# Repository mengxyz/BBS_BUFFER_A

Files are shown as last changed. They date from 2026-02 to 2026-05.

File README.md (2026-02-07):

# BBS_BUFFER_A
### BAMBU Filament Buffer alternative with super cheap component
Minimal, fast, and hardware‑focused firmware for the CH32V003.  
This project currently ships a clean **ADC → PWM** control loop with **button‑driven calibration** stored in flash.

Built with GPT Codex 5.2.

Based on the original BBS Buffer A project: `https://github.com/4061N/BBS-Buffer-A`

## Highlights
- 10‑bit ADC read on PA2, mapped to PWM duty.
- PWM output on PC4 (TIM1 CH4) by default.
- Short/long press calibration on PC1:
  - Short press → save **min ADC**
  - Long press → save **max ADC**
- Calibration stored in on‑chip flash (EEPROM‑style).
- UART debug prints on PD5 (115200 8N1).

## Quick Start (PlatformIO)
From repo root:
```bash
pio run -e genericCH32V003A4M6
pio run -t upload -e genericCH32V003A4M6
```

## Pin Map (current firmware)
- **PA2**: ADC input
- **PC4**: PWM output (TIM1 CH4)
- **PC1**: Button input (internal pull‑up, active‑low)
- **PD5**: UART TX (115200 8N1)
- **PC2**: WS2812 data (optional, not used by default)

## Calibration Behavior
On **button release**:
- Press < `BUTTON_LONG_MS` → save min ADC
- Press ≥ `BUTTON_LONG_MS` → save max ADC

Saved values are written to the **last flash page** and loaded on boot.  
If flash data is invalid, firmware falls back to defaults.

## Key Config Macros (src/main.c)
- `USE_CALC` — enable/disable flash calibration
- `UART_ENABLE` — UART debug prints
- `PWM_USE_PC4` — choose PWM pin (PC4 vs PA1)
- `ADC_MIN_DEFAULT`, `ADC_MAX_DEFAULT` — fallback range
- `BUTTON_LONG_MS` — long‑press threshold

## Files of Interest
- `src/main.c` — main control loop
- `src/calibration.c` / `include/calibration.h` — flash storage helpers

## Notes
Flash writes erase a full page. Avoid saving excessively in tight loops.

## Recommended 3D Model
[BBS Buffer A XMCU Series Buffer 3D model](https://makerworld.com/en/models/2035894-bbs-buffer-a-xmcu-series-buffer#profileId-2196013)

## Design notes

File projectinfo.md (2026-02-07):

project ported bbs_buffer in /ref folder form ch32v203 to ch32v003

pin def
PC1 OL_ADC
PC2 SYS_RGB
PC4 ADC_1 choose once PC4 / PA1 use to read HALL voltage
PA1 ADC_2
PA2 HALL_OUT pwm out
PD1 programing pin -> UART TX for debug

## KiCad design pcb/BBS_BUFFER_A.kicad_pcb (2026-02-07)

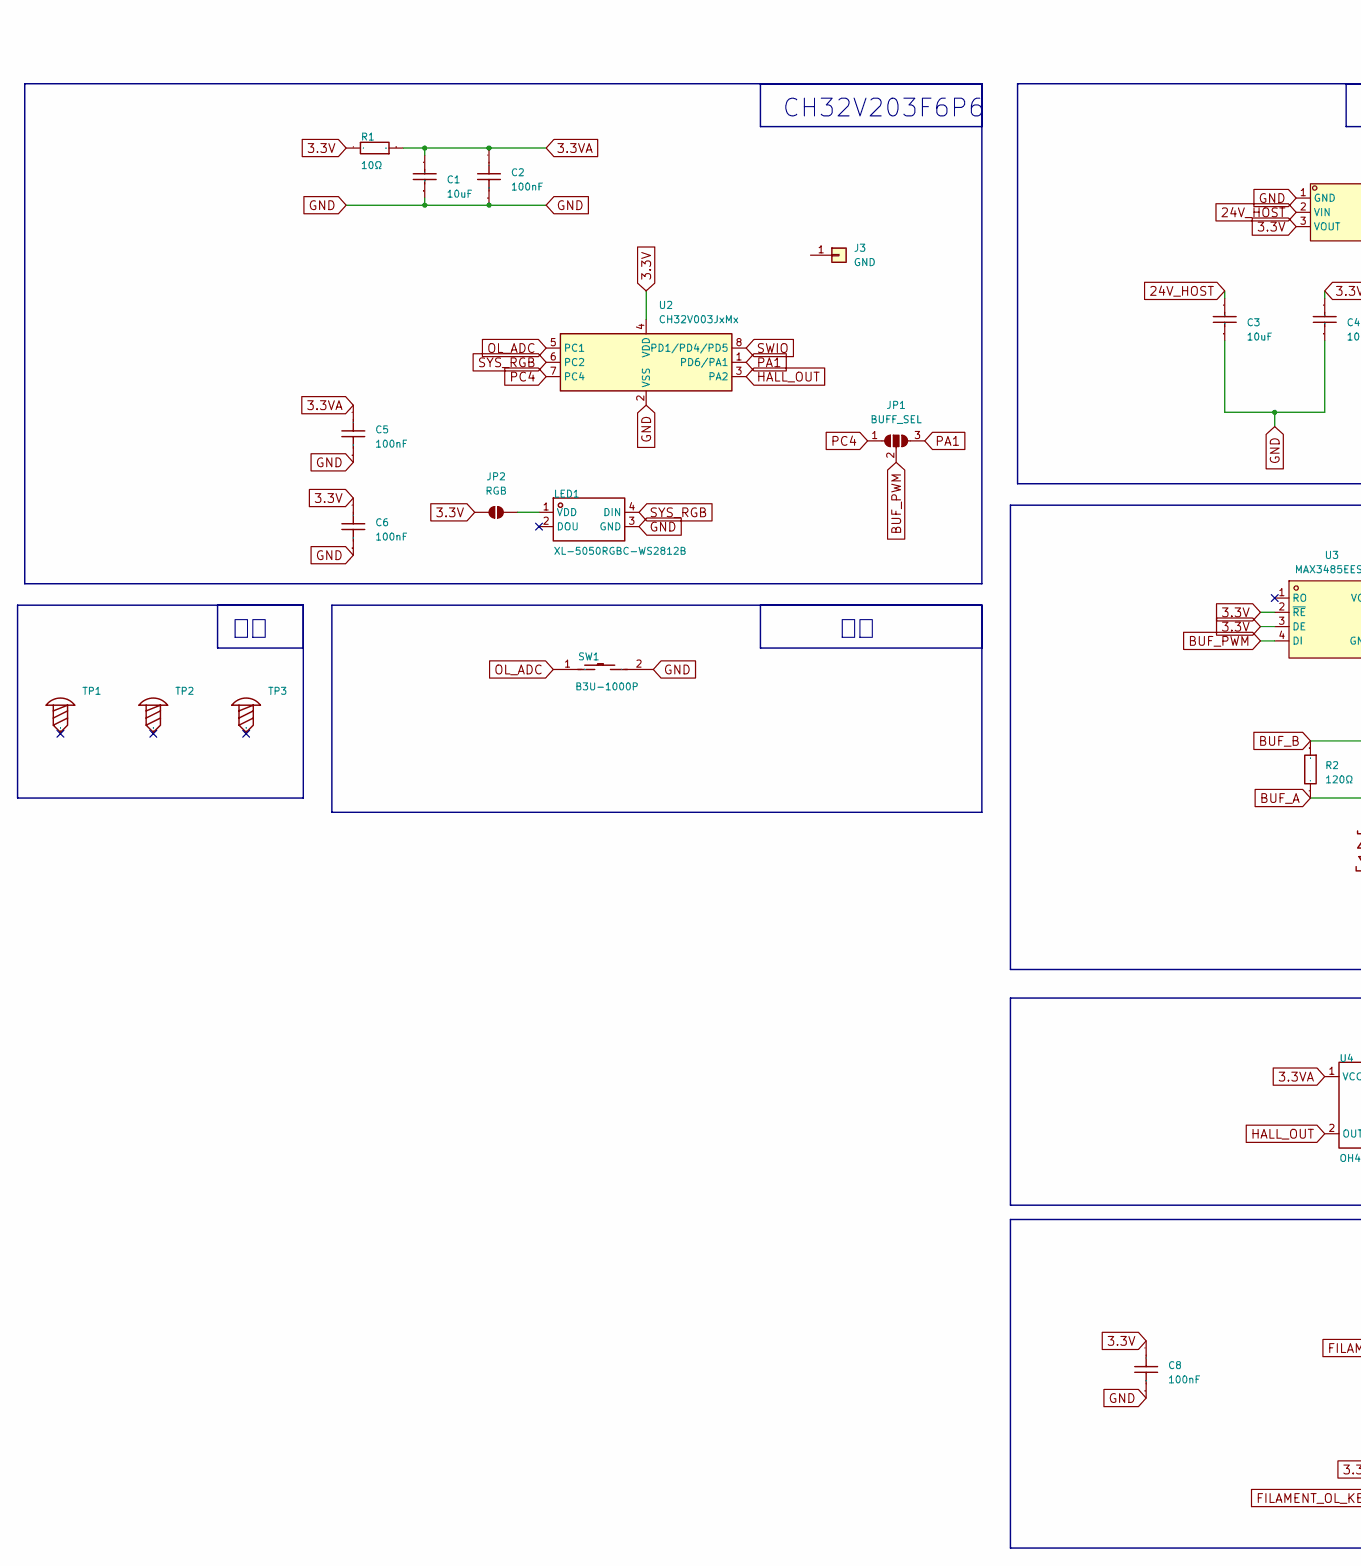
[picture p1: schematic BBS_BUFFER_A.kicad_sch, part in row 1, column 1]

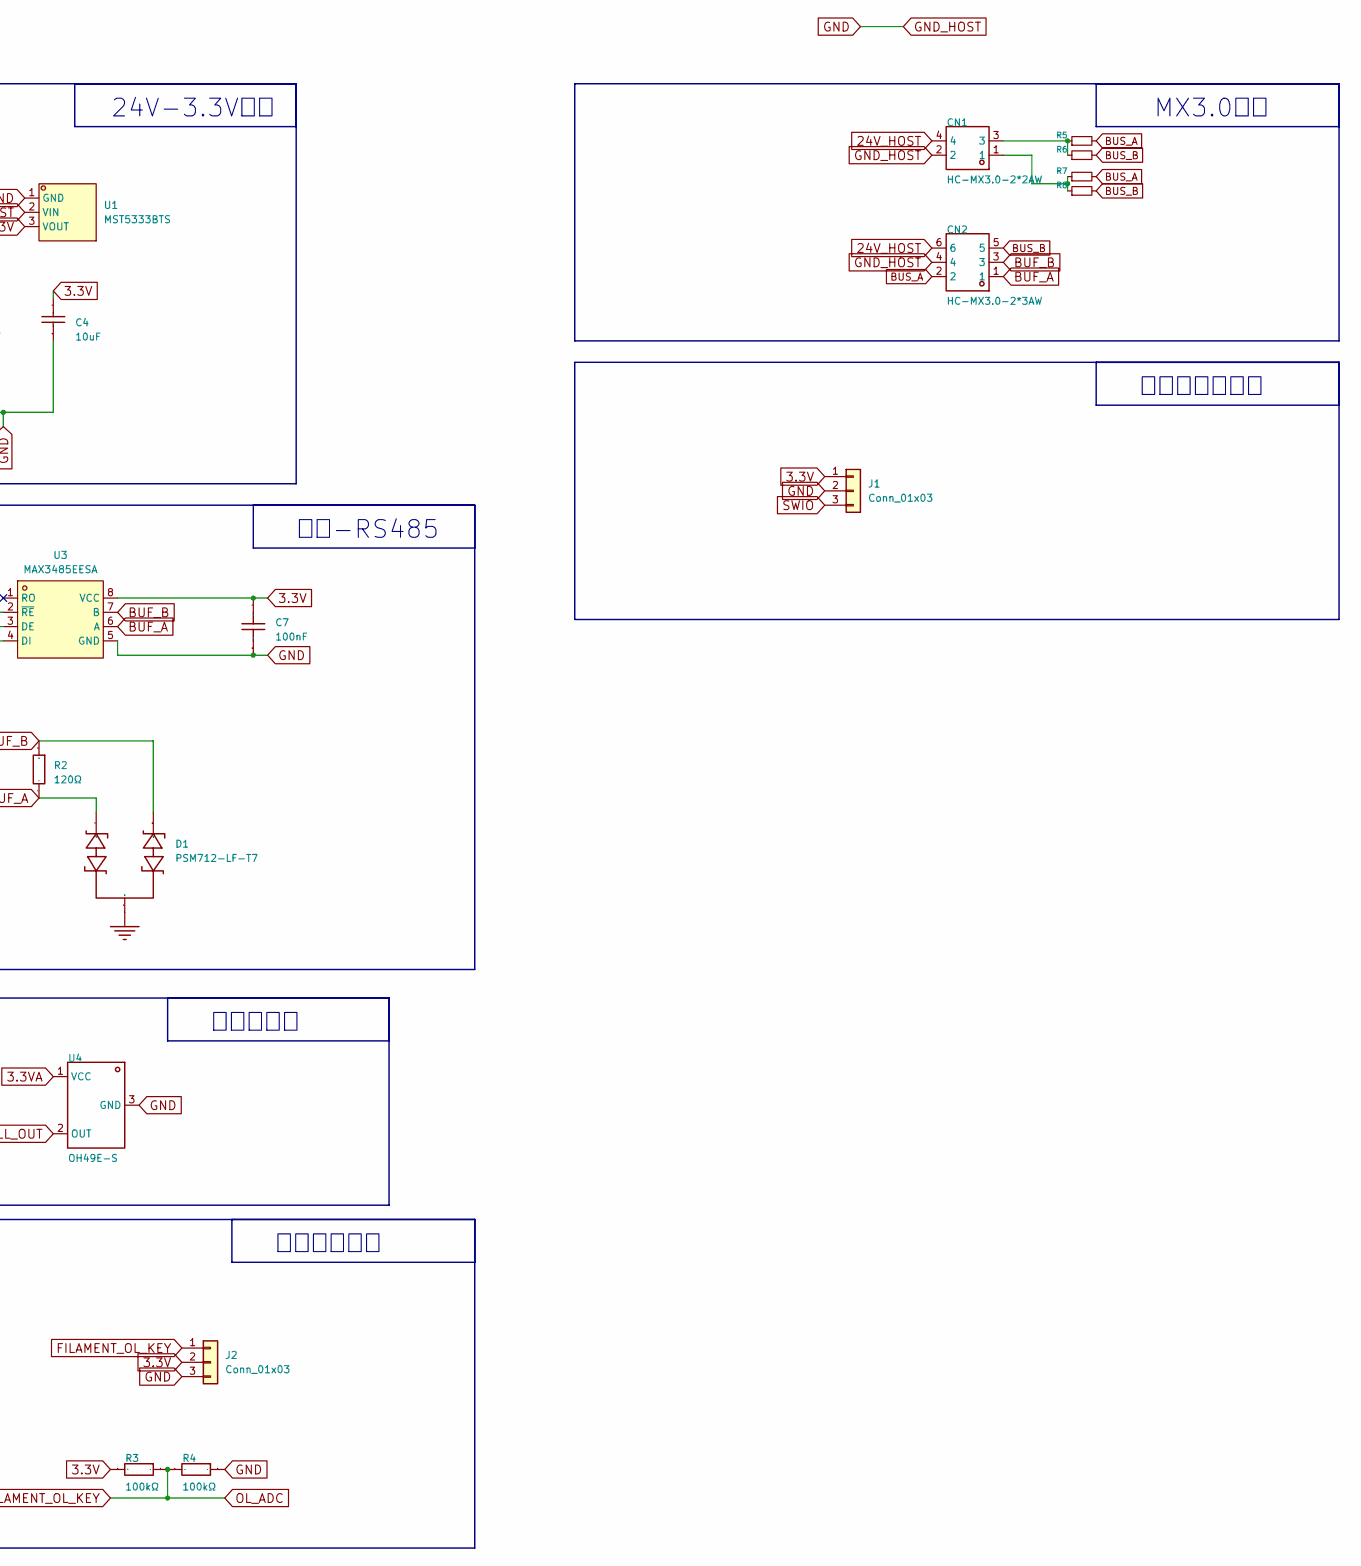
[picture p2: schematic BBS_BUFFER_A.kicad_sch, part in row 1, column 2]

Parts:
C1, C3, C4: 10uF; C_1206_3216Metric; Manufacturer Part CL31A106KBHNNNE; LCSC Part Name 10uF ±10% 50V
C2, C5, C6, C7, C8: 100nF; C_0603_1608Metric; Tolerance ±10%; Voltage Rated 50V; Manufacturer Part CC0603KRX7R9BB104; LCSC Part Name 100nF ±10% 50V
CN1: HC-MX3.0-2*2AW; CONN-TH_4P-P3.00_HC-MX3.0-2X2AW_1; Manufacturer Part HC-MX3.0-2*2AW; LCSC Part Name 2x2P 间距:3mm 弯插 系列:Micro-Fit(MX 3.0)
CN2: HC-MX3.0-2*3AW; CONN-TH_6P-P3.00_HC-MX3.0-2X3AW_1; Manufacturer Part HC-MX3.0-2*3AW; LCSC Part Name 2x3P 间距:3mm 弯插 系列:Micro-Fit(MX 3.0)
D1: PSM712-LF-T7; SOT-23-3_L3.0-W1.7-P0.95-LS2.9-BR; Manufacturer Part PSM712-LF-T7; LCSC Part Name PSM712-LF-T7
J1, J2: Conn_01x03; PinHeader_1x03_P2.54mm_Vertical
J3: GND; PinHeader_1x01_P2.54mm_Vertical
JP1: BUFF_SEL; SolderJumper-3_P2.0mm_Open_TrianglePad1.0x1.5mm
JP2: RGB; R_0402_1005Metric
LED1: XL-5050RGBC-WS2812B; LED-SMD_4P-L5.0-W5.0-BL_XL-5050RGBC; Manufacturer Part XL-5050RGBC-WS2812B; LCSC Part Name XL-5050RGBC-WS2812B
R1: 10Ω; C_0603_1608Metric; Manufacturer Part 0603WAF100JT5E; LCSC Part Name 10Ω ±1% 100mW 厚膜电阻
R2: 120Ω; R_0603_1608Metric; Manufacturer Part 0603WAF1200T5E; LCSC Part Name 120Ω ±1% 100mW 厚膜电阻
R3, R4: 100kΩ; R_0603_1608Metric; Manufacturer Part 0603WAF1003T5E; LCSC Part Name 100kΩ ±1% 100mW 厚膜电阻
R5, R6, R7, R8: R_0402_1005Metric
SW1: B3U-1000P; SW-SMD_L4.0-W3.0-LS5.0; Manufacturer Part B3U-1000P; LCSC Part Name B3U-1000P
TP1, TP2, TP3: MountingHole_2.2mm_M2_DIN965
U1: MST5333BTS; SOT-89-3_L4.5-W2.5-P1.50-LS4.2-BR; LCSC Part C324582
U2: CH32V003JxMx; JEITA_SOIC-8_3.9x4.9mm_P1.27mm
U3: MAX3485EESA; SOIC-8_L4.9-W3.9-P1.27-LS6.0-BL; LCSC Part C9943
U4: OH49E-S; SOT-23-3_L2.9-W1.6-P1.90-LS2.8-BR; Manufacturer Part OH49E-S; LCSC Part Name 线性霍尔开关电路

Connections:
3.3V: C4.2, C6.2, C7.2, C8.2, J1.1, J2.2, JP2.1 (A), R1.2, R3.2, U1.3 (VOUT), U2.4 (VDD), U3.2 (~RE), U3.3 (DE), U3.8 (VCC)
3.3VA: C1.2, C2.2, C5.2, R1.1, U4.1 (VCC)
24V_HOST: C3.2, CN1.4, CN2.6, U1.2 (VIN)
BUF_A: CN2.1, D1.2 (A1), R2.2, U3.6 (A)
BUF_B: CN2.3, D1.1 (A1), R2.1, U3.7 (B)
BUF_PWM: JP1.2 (C), U3.4 (DI)
BUS_A: CN2.2, R5.2, R7.2
BUS_B: CN2.5, R6.2, R8.2
FILAMENT_OL_KEY: J2.1, R3.1, R4.2, SW1.1, U2.5 (PC1)
GND: C1.1, C2.1, C3.1, C4.1, C5.1, C6.1, C7.1, C8.1, CN1.2, CN2.4, D1.3 (K), J1.2, J2.3, LED1.3 (GND), R4.1, SW1.2, U1.1 (GND), U2.2 (VSS), U3.5 (GND), U4.3 (GND)
HALL_OUT: U2.3 (PA2), U4.2 (OUT)
unnamed: CN1.1, R7.1, R8.1
unnamed: CN1.3, R5.1, R6.1
unnamed: JP2.2 (B), LED1.1 (VDD)
PA1: JP1.3 (B), U2.1 (PD6/PA1)
PC4: JP1.1 (A), U2.7 (PC4)
SWIO: J1.3, U2.8 (PD1/PD4/PD5)
SYS_RGB: LED1.4 (DIN), U2.6 (PC2)

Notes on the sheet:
烧录和调试接口
耗材断料检测
霍尔传感器
MX3.0接口
CH32V203F6P6
串口-RS485
24V-3.3V电源

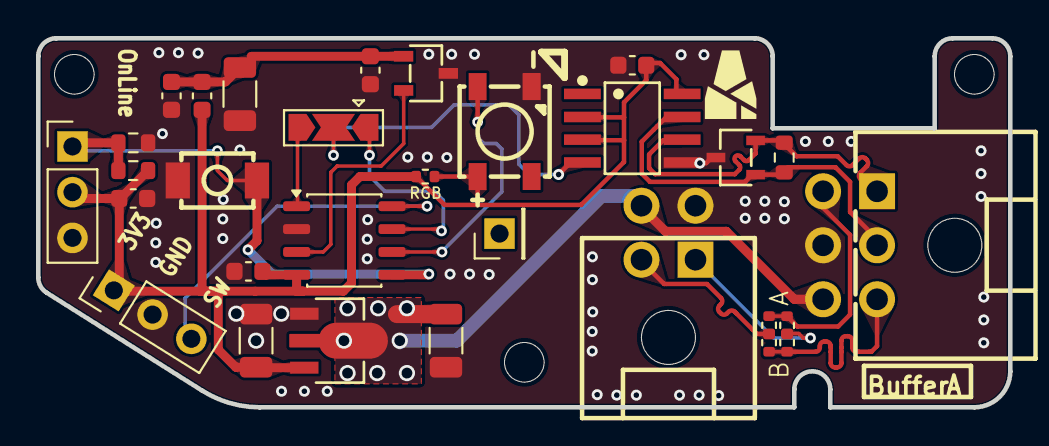
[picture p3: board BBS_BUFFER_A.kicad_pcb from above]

Board: 2 copper layers, 54.0 x 20.5 mm, 33 parts (0 on the bottom side), 18 nets.

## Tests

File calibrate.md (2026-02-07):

```
- idle press button to save min adc 
- pull buffer long press btn to save mz adc

recomend pull first then idle
ws2182 not work
```

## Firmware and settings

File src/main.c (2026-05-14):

// Could be defined here, or in the processor defines.
#define SYSTEM_CORE_CLOCK 48000000
#define USE_CALC 1

#include "ch32v00x.h"
#if USE_CALC
#include "calibration.h"
#endif

#define APB_CLOCK SYSTEM_CORE_CLOCK
#define ADC_MAX 1023u
#define ADC_MIN_DEFAULT 0
#define ADC_MAX_DEFAULT 1023u
#define UART_ENABLE 0
#define BUTTON_DEBOUNCE_MS 20u
#define BUTTON_LONG_MS 1000u
#define PWM_USE_PC4 1 // 1 = TIM1 CH4 on PC4 (hardware PWM). 0 = TIM2 ISR on PA1.
#define PWM_DUTY_MIN_PERCENT 15u // Clamp output duty lower bound (0..100).
#define PWM_DUTY_MAX_PERCENT 90u // Clamp output duty upper bound (0..100).
#define WDT_ENABLE 0
#define WDT_PRESCALER IWDG_Prescaler_64
#define WDT_RELOAD 625u // ~1s at LSI ~40kHz: 40k/64 = 625Hz.
#define ADC_DMA_SAMPLES 16u

static volatile uint16_t adc_dma_buf[ADC_DMA_SAMPLES];

#if PWM_USE_PC4
static void SetupPWM_PC4_10k(void)
{
	// Enable GPIOC + AFIO + TIM1 clocks.
	RCC->APB2PCENR |= RCC_IOPCEN | RCC_AFIOEN | RCC_TIM1EN;

	// Reset TIM1 to a known state.
	RCC->APB2PRSTR |= RCC_TIM1RST;
	RCC->APB2PRSTR &= ~RCC_TIM1RST;

	// PC4 as AF push-pull, 50MHz.
	GPIOC->CFGLR &= ~(0xF << (4 * 4));
	GPIOC->CFGLR |= (GPIO_Speed_50MHz | GPIO_CNF_OUT_PP_AF) << (4 * 4);

	// TIM1 base: 48MHz / (PSC+1) / (ARR+1) = 10kHz
	TIM1->CTLR1 = 0;
	TIM1->CTLR2 = 0;
	TIM1->SMCFGR = 0;
	TIM1->PSC = 47;     // 48MHz / 48 = 1MHz
	TIM1->ATRLR = 99;   // 1MHz / 100 = 10kHz
	TIM1->CH4CVR = 50;  // start at 50% duty

	// PWM mode 1 on CH4, preload enable.
	TIM1->CHCTLR2 &= ~TIM_OC4M;
	TIM1->CHCTLR2 |= TIM_OC4PE | TIM_OC4M_1 | TIM_OC4M_2;
	TIM1->CCER |= TIM_CC4E;

	// Enable main output and start.
	TIM1->BDTR |= TIM_MOE;
	TIM1->SWEVGR = TIM_UG;
	TIM1->CTLR1 |= TIM_ARPE | TIM_CEN;
}

#else
static void SetupPWM_PA1_10k(void)
{
	// Enable GPIOA + TIM2 clocks.
	RCC->APB2PCENR |= RCC_IOPAEN;
	RCC->APB1PCENR |= RCC_TIM2EN;

	// Reset TIM2 to a known state.
	RCC->APB1PRSTR |= RCC_TIM2RST;
	RCC->APB1PRSTR &= ~RCC_TIM2RST;

	// PA1 as GPIO output (toggled in the ISR).
	GPIOA->CFGLR &= ~(0xF << (4 * 1));
	GPIOA->CFGLR |= (GPIO_Speed_50MHz | GPIO_CNF_OUT_PP) << (4 * 1);
	GPIOA->BCR = 1 << 1;

	// TIM2 base: 48MHz / (PSC+1) / (ARR+1) = 10kHz
	TIM2->CTLR1 = 0;
	TIM2->CTLR2 = 0;
	TIM2->SMCFGR = 0;
	TIM2->CHCTLR1 &= ~TIM_CC1S; // CC1 as output compare
	TIM2->PSC = 47;     // 48MHz / 48 = 1MHz
	TIM2->ATRLR = 99;   // 1MHz / 100 = 10kHz
	TIM2->CH1CVR = 50;  // start at 50% duty

	// Enable update + CC1 interrupts.
	TIM2->DMAINTENR |= TIM_UIE | TIM_CC1IE;
	NVIC_EnableIRQ(TIM2_IRQn);

	// Load registers and start.
	TIM2->SWEVGR = TIM_UG;
	TIM2->CTLR1 |= TIM_ARPE | TIM_CEN;
	__enable_irq();
}

void TIM2_IRQHandler(void) __attribute__((interrupt("WCH-Interrupt-fast")));
void TIM2_IRQHandler(void)
{
	uint16_t status = TIM2->INTFR;

	if (status & TIM_UIF)
	{
		TIM2->INTFR &= ~TIM_UIF;
		GPIOA->BSHR = 1 << 1;
	}
	if (status & TIM_CC1IF)
	{
		TIM2->INTFR &= ~TIM_CC1IF;
		GPIOA->BCR = 1 << 1;
	}
}
#endif

static void SetupADC_DMA_PA2(void)
{
	RCC->APB2PCENR |= RCC_IOPAEN | RCC_ADC1EN;
	RCC->AHBPCENR  |= RCC_DMA1EN;

	// ADC clock: 48MHz / 4 = 12MHz (max 14MHz)
	RCC->CFGR0 &= ~RCC_ADCPRE;
	RCC->CFGR0 |= RCC_ADCPRE_DIV4;

	// PA2 as analog input.
	GPIOA->CFGLR &= ~(0xF << (4 * 2));
	GPIOA->CFGLR |= (GPIO_CNF_IN_ANALOG | GPIO_SPEED_IN) << (4 * 2);

	// DMA1 Channel1: ADC1->RDATAR -> adc_dma_buf, circular, 16-bit.
	DMA1_Channel1->CFGR  = 0;
	DMA1_Channel1->CNTR  = ADC_DMA_SAMPLES;
	DMA1_Channel1->PADDR = (uint32_t)&ADC1->RDATAR;
	DMA1_Channel1->MADDR = (uint32_t)adc_dma_buf;
	DMA1_Channel1->CFGR  =
		DMA_CFGR1_MINC                    |  // increment memory address
		DMA_CFGR1_CIRC                    |  // circular: auto-reload CNTR
		DMA_CFGR1_PSIZE_0                 |  // peripheral 16-bit
		DMA_CFGR1_MSIZE_0                 |  // memory 16-bit
		DMA_CFGR1_PL_1 | DMA_CFGR1_PL_0  |  // very high priority
		DMA_CFGR1_EN;

	// Calibrate before enabling continuous+DMA.
	ADC1->CTLR1 = 0;
	ADC1->CTLR2 = ADC_ADON;
	ADC1->CTLR2 |= ADC_RSTCAL;
	while (ADC1->CTLR2 & ADC_RSTCAL) {}
	ADC1->CTLR2 |= ADC_CAL;
	while (ADC1->CTLR2 & ADC_CAL) {}

	// Continuous mode + DMA on channel 0, 241-cycle sample time.
	ADC1->CTLR2 &= ~ADC_EXTSEL;
	ADC1->CTLR2 |= ADC_ExternalTrigConv_None | ADC_EXTTRIG | ADC_DMA | ADC_CONT;
	ADC1->RSQR1  = 0;
	ADC1->RSQR2  = 0;
	ADC1->RSQR3  = ADC_Channel_0;
	ADC1->SAMPTR2 &= ~ADC_SMP0;
	ADC1->SAMPTR2 |= ADC_SampleTime_241Cycles;

	// Start — DMA fills buffer continuously from here.
	ADC1->CTLR2 |= ADC_SWSTART;
}

static void SetupInput_PC1_Pullup(void)
{
	RCC->APB2PCENR |= RCC_IOPCEN;

	// PC1 input with pull-up/down.
	GPIOC->CFGLR &= ~(0xF << (4 * 1));
	GPIOC->CFGLR |= (GPIO_SPEED_IN | GPIO_CNF_IN_PUPD) << (4 * 1);

	GPIOC->BSHR = 1 << 1; // pull-up (active low)
}

static uint16_t ReadADC_Average(void)
{
	uint32_t sum = 0;
	for (uint8_t i = 0; i < ADC_DMA_SAMPLES; i++)
		sum += adc_dma_buf[i];
	return (uint16_t)(sum / ADC_DMA_SAMPLES);
}

static uint8_t ButtonPressed(void)
{
	return (GPIOC->INDR & (1 << 1)) ? 0u : 1u;
}

#if WDT_ENABLE
static void SetupWDT(void)
{
	IWDG->CTLR = IWDG_WriteAccess_Enable;
	IWDG->PSCR = WDT_PRESCALER;
	IWDG->RLDR = (WDT_RELOAD & IWDG_RL);
	while (IWDG->STATR & (IWDG_PVU | IWDG_RVU)) {}
	IWDG->CTLR = CTLR_KEY_Reload;
	IWDG->CTLR = CTLR_KEY_Enable;
}

static inline void FeedWDT(void)
{
	IWDG->CTLR = CTLR_KEY_Reload;
}
#endif

int main()
{
	SystemInit48HSI();
#if UART_ENABLE
	SetupUART(UART_BRR);
	// printf("btn test\r\n");
#endif
	#if PWM_USE_PC4
	SetupPWM_PC4_10k();
	#else
	SetupPWM_PA1_10k();
	#endif
	#if USE_CALC
	SetupInput_PC1_Pullup();
	#endif
	SetupADC_DMA_PA2();
#if WDT_ENABLE
	SetupWDT();
#endif
	#if USE_CALC
	calib_data_t calib = { ADC_MIN_DEFAULT, ADC_MAX_DEFAULT };
	if (!calib_load(&calib) || calib.adc_max <= calib.adc_min)
	{
		calib.adc_min = ADC_MIN_DEFAULT;
		calib.adc_max = ADC_MAX_DEFAULT;
	}
	uint16_t press_ms = 0;
	uint8_t pressed_prev = 0;
	#endif
	
	while(1)
	{
		uint16_t adc_raw = ReadADC_Average();
		uint16_t adc = adc_raw;
		#if PWM_USE_PC4
		uint16_t arr = TIM1->ATRLR;
		#else
		uint16_t arr = TIM2->ATRLR;
		#endif
#if USE_CALC
		if (adc < calib.adc_min)
			adc = calib.adc_min;
		if (adc > calib.adc_max)
			adc = calib.adc_max;

		uint16_t span = (uint16_t)(calib.adc_max - calib.adc_min);
		uint16_t adj = (uint16_t)(adc - calib.adc_min);
#else
		if (adc < ADC_MIN_DEFAULT)
			adc = ADC_MIN_DEFAULT;
		if (adc > ADC_MAX_DEFAULT)
			adc = ADC_MAX_DEFAULT;

		uint16_t span = (uint16_t)(ADC_MAX_DEFAULT - ADC_MIN_DEFAULT);
		uint16_t adj = (uint16_t)(adc - ADC_MIN_DEFAULT);
#endif
		uint16_t ccr = (uint16_t)((adj * (uint32_t)(arr + 1)) / (span + 1));

		// Clamp mapped duty to user-defined min/max percentages.
		uint16_t ccr_min = (uint16_t)(((arr + 1u) * PWM_DUTY_MIN_PERCENT) / 100u);
		uint16_t ccr_max = (uint16_t)(((arr + 1u) * PWM_DUTY_MAX_PERCENT) / 100u);
		if (ccr_min == 0)
			ccr_min = 1;
		if (ccr_max >= arr)
			ccr_max = arr - 1;
		if (ccr_max <= ccr_min)
			ccr_max = (uint16_t)(ccr_min + 1u);

		if (ccr < ccr_min)
			ccr = ccr_min;
		if (ccr > ccr_max)
			ccr = ccr_max;

		#if PWM_USE_PC4
		TIM1->CH4CVR = ccr;
		#else
		TIM2->CH1CVR = ccr;
		#endif

#if USE_CALC
		uint8_t pressed = ButtonPressed();
		if (pressed)
		{
			if (press_ms < 60000u)
				press_ms = (uint16_t)(press_ms + 5u);
		}
		else if (pressed_prev)
		{
			if (press_ms >= BUTTON_LONG_MS)
			{
				calib.adc_max = adc_raw;
				if (calib.adc_max <= calib.adc_min)
					calib.adc_min = (calib.adc_max > 0) ? (uint16_t)(calib.adc_max - 1) : 0;
				calib_save(&calib);
				// printf("save max=%u\r\n", calib.adc_max);
			}
			else if (press_ms >= BUTTON_DEBOUNCE_MS)
			{
				calib.adc_min = adc_raw;
				if (calib.adc_min >= calib.adc_max)
					calib.adc_max = (uint16_t)(calib.adc_min + 1);
				calib_save(&calib);
				// printf("save min=%u\r\n", calib.adc_min);
			}
			press_ms = 0;
		}
		pressed_prev = pressed;
#endif

#if WDT_ENABLE
		FeedWDT();
#endif
		Delay_Ms(5);
	}
}

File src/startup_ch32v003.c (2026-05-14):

/*
	C version of CH32V003 Startup .s file from WCH
	This file is public domain where possible or the following where not:
	Copyright 2023 Charles Lohr, under the MIT-x11 or NewBSD licenses, you choose.
*/

#include <stdint.h>
#include <ch32v00x.h>

int main() __attribute__((used));
void SystemInit( void ) __attribute__((used));

void InterruptVector()         __attribute__((naked)) __attribute((section(".init"))) __attribute__((used));
void handle_reset()            __attribute__((naked)) __attribute((section(".text.handle_reset"))) __attribute__((used));
void DefaultIRQHandler( void ) __attribute__((section(".text.vector_handler"))) __attribute__((naked)) __attribute__((used));

extern uint32_t * _sbss;
extern uint32_t * _ebss;
extern uint32_t * _data_lma;
extern uint32_t * _data_vma;
extern uint32_t * _edata;


// If you don't override a specific handler, it will just spin forever.
void DefaultIRQHandler( void )
{
	// Infinite Loop
	asm volatile( "1: j 1b" );
}

// This makes it so that all of the interrupt handlers just alias to
// DefaultIRQHandler unless they are individually overridden.
void NMI_Handler( void )                 __attribute__((section(".text.vector_handler"))) __attribute((weak,alias("DefaultIRQHandler"))) __attribute__((used));
void HardFault_Handler( void )           __attribute__((section(".text.vector_handler"))) __attribute((weak,alias("DefaultIRQHandler"))) __attribute__((used));
void SysTick_Handler( void )             __attribute__((section(".text.vector_handler"))) __attribute((weak,alias("DefaultIRQHandler"))) __attribute__((used));
void SW_Handler( void )                  __attribute__((section(".text.vector_handler"))) __attribute((weak,alias("DefaultIRQHandler"))) __attribute__((used));
void WWDG_IRQHandler( void )             __attribute__((section(".text.vector_handler"))) __attribute((weak,alias("DefaultIRQHandler"))) __attribute__((used));
void PVD_IRQHandler( void )              __attribute__((section(".text.vector_handler"))) __attribute((weak,alias("DefaultIRQHandler"))) __attribute__((used));
void FLASH_IRQHandler( void )            __attribute__((section(".text.vector_handler"))) __attribute((weak,alias("DefaultIRQHandler"))) __attribute__((used));
void RCC_IRQHandler( void )              __attribute__((section(".text.vector_handler"))) __attribute((weak,alias("DefaultIRQHandler"))) __attribute__((used));
void EXTI7_0_IRQHandler( void )          __attribute__((section(".text.vector_handler"))) __attribute((weak,alias("DefaultIRQHandler"))) __attribute__((used));
void AWU_IRQHandler( void )              __attribute__((section(".text.vector_handler"))) __attribute((weak,alias("DefaultIRQHandler"))) __attribute__((used));
void DMA1_Channel1_IRQHandler( void )    __attribute__((section(".text.vector_handler"))) __attribute((weak,alias("DefaultIRQHandler"))) __attribute__((used));
void DMA1_Channel2_IRQHandler( void )    __attribute__((section(".text.vector_handler"))) __attribute((weak,alias("DefaultIRQHandler"))) __attribute__((used));
void DMA1_Channel3_IRQHandler( void )    __attribute__((section(".text.vector_handler"))) __attribute((weak,alias("DefaultIRQHandler"))) __attribute__((used));
void DMA1_Channel4_IRQHandler( void )    __attribute__((section(".text.vector_handler"))) __attribute((weak,alias("DefaultIRQHandler"))) __attribute__((used));
void DMA1_Channel5_IRQHandler( void )    __attribute__((section(".text.vector_handler"))) __attribute((weak,alias("DefaultIRQHandler"))) __attribute__((used));
void DMA1_Channel6_IRQHandler( void )    __attribute__((section(".text.vector_handler"))) __attribute((weak,alias("DefaultIRQHandler"))) __attribute__((used));
void DMA1_Channel7_IRQHandler( void )    __attribute__((section(".text.vector_handler"))) __attribute((weak,alias("DefaultIRQHandler"))) __attribute__((used));
void ADC1_IRQHandler( void )             __attribute__((section(".text.vector_handler"))) __attribute((weak,alias("DefaultIRQHandler"))) __attribute__((used));
void I2C1_EV_IRQHandler( void )          __attribute__((section(".text.vector_handler"))) __attribute((weak,alias("DefaultIRQHandler"))) __attribute__((used));
void I2C1_ER_IRQHandler( void )          __attribute__((section(".text.vector_handler"))) __attribute((weak,alias("DefaultIRQHandler"))) __attribute__((used));
void USART1_IRQHandler( void )           __attribute__((section(".text.vector_handler"))) __attribute((weak,alias("DefaultIRQHandler"))) __attribute__((used));
void SPI1_IRQHandler( void )             __attribute__((section(".text.vector_handler"))) __attribute((weak,alias("DefaultIRQHandler"))) __attribute__((used));
void TIM1_BRK_IRQHandler( void )         __attribute__((section(".text.vector_handler"))) __attribute((weak,alias("DefaultIRQHandler"))) __attribute__((used));
void TIM1_UP_IRQHandler( void )          __attribute__((section(".text.vector_handler"))) __attribute((weak,alias("DefaultIRQHandler"))) __attribute__((used));
void TIM1_TRG_COM_IRQHandler( void )     __attribute__((section(".text.vector_handler"))) __attribute((weak,alias("DefaultIRQHandler"))) __attribute__((used));
void TIM1_CC_IRQHandler( void )          __attribute__((section(".text.vector_handler"))) __attribute((weak,alias("DefaultIRQHandler"))) __attribute__((used));
void TIM2_IRQHandler( void )             __attribute__((section(".text.vector_handler"))) __attribute((weak,alias("DefaultIRQHandler"))) __attribute__((used));
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

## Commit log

2026-02-14 change min max duty fix ams not detect buffer if pwm is lower
    [main.c]
2026-05-14 fixed pwm frq not close 10Khz - improve adc dma
    [main.c, startup_ch32v003.c]
